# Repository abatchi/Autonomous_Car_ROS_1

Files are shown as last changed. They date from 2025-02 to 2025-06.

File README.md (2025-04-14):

# Autonomous Systems Project Team 08

# 🚀 Milestone 2

## 📌 Overview
Milestone 2 focuses on enhancements in software, simulation, and Hardware testing of the vehicle and motors. This phase includes crucial improvements in **Teleop**, **OLR (Open Loop Response)**, and system integration.

## 📁 Project Structure
The following key components are included in this milestone:

- **`python_scripts/`**: Contains essential scripts for teleoperation and OLR.
- **`launch/`**: Houses the necessary launch files for initializing the system.
- **Additional components**: Any supplementary configurations, ROS packages, or dependencies required for smooth operation.

# 📜 Milestone 1 Deliverables
For reference, the deliverables from Milestone 1 can be found in the following directories:

- **Hardware Deliverables:** Located in  
  📂 `Autonomous_Systems_Project_Team_08/Milestone1/Hardware_Milestone_01_Team_08/`
- **Simulation Deliverables:** Located in  
  📂 `Autonomous_Systems_Project_Team_08/Milestone1/Simulation_Milestone_01_Team_08/`

These directories contain all the necessary resources, including **hardware setup instructions for the Raspberry Pi 4B** and **simulation-based deliverables** from the first milestone.

## 📌 Next Steps
- Fine-tune the teleoperation and OLR functionalities.
- Validate performance through both **simulation** and **real-world testing**.
- Prepare documentation and further refinements for the next milestone.

---
📌 *This project is part of the Autonomous Systems course, developed by Team 08.* 🚀

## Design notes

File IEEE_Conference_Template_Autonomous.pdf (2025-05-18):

# 1/10 scale Autonomous Vehicle using ROS

1

st Nabil Hassan
Mechatronics Department
German University in Cairo Cairo, Egypt
nabil.hassan@student.guc.edu.eg

2

nd Yassin Eissa
Mechatronics Department
German University in Cairo Cairo, Egypt
yassin.eissa@student.guc.edu.eg

3

rd Mahmoud Assem
Mechatronics Department
German University in Cairo Cairo, Egypt
mahmoud.elkattan@student.guc.edu.eg

4

th Mohamed Mohy
Mechatronics Department
German University in Cairo Cairo, Egypt
mohamed.mohyeldin@student.guc.edu.eg

5

th Ahmed Akkad
Mechatronics Department
German University in Cairo Cairo, Egypt
ahmed.alakkad@student.guc.edu.eg

Abstract—This paper presents the development and implementation of a low-cost, small-scale autonomous ground vehicle designed for structured environments. The system adopts a modular architecture composed of a Raspberry Pi as the onboard computer for high-level processing and an Arduino Nano as the low-level controller for motor actuation and sensor interfacing. The vehicle integrates an Inertial Measurement Unit (IMU) for heading correction and wheel encoders for real-time speed estimation. A Stanley controller is utilized for lateral path tracking, while a PID controller governs longitudinal velocity. The software stack is built using the Robot Operating System (ROS), enabling efficient communication between system components and real-time decision-making. The proposed platform demonstrates reliable autonomous navigation capabilities and serves as an accessible and scalable solution for research and educational applications in the field of autonomous systems. Index Terms—Autonomous ground vehicle, ROS, Raspberry Pi, Arduino Nano, Stanley controller, PID control, IMU, wheel encoders, embedded systems, mobile robotics, path tracking.

I. INTRODUCTION
Autonomous vehicles are a rapidly evolving field at the intersection of robotics, artificial intelligence, and control systems. Their development promises to transform the way humans transport goods and themselves, offering significant advantages in safety, efficiency, scalability, and sustainability. While full-scale autonomous vehicles are the focus of major industrial efforts and commercial deployments, scaled-down autonomous platforms have emerged as powerful tools for research and education. Among these, 1/10 scale autonomous cars have gained considerable traction due to their affordability, safety, ease of experimentation, and strong community support.
A particularly prominent framework in this domain is the F1Tenth Autonomous Racing Platform, which provides a standardized, reproducible, and open-source platform for developing and benchmarking autonomous driving algorithms at 1/10 scale. Built on top of the Robot Operating System (ROS), the F1Tenth platform offers modular tools and software packages for perception, planning, and control, enabling researchers and students to implement real-world autonomous systems in a simulated or physical environment. The platform is supported by an international community and regularly features in autonomous racing competitions, fostering innovation and collaboration.
The development of autonomous vehicles, even at reduced scale, involves solving several complex tasks: localization, mapping, obstacle detection, trajectory planning, and control. These tasks must operate concurrently under real-time constraints and interact through a tightly integrated software architecture. ROS facilitates this integration by providing communication tools, simulation environments like Gazebo, and driver libraries for interfacing with sensors and actuators. As a middleware, ROS enables distributed development and modular testing, which are essential for the layered design of autonomous systems.
In this work, we present the design and implementation of a 1/10 scale autonomous vehicle built upon the principles of the F1Tenth platform and ROS architecture. The system was developed to perform autonomous lane-following and obstacle avoidance using real-time sensor feedback and closed-loop control. A Raspberry Pi 4 was used as the onboard high-level computer, running ROS nodes responsible for perception, planning, and control. Meanwhile, an Arduino Nano served as the low-level controller to directly manage motor speed and steering commands.
The localization system employed encoder data for speed estimation and an Inertial Measurement Unit (IMU) for heading correction, fused to provide accurate pose estimation in the absence of GPS. For lateral control, we implemented the Stanley Controller, a well-known algorithm used in path tracking for autonomous vehicles due to its simplicity and robustness to lateral errors. For longitudinal control, a classic PID controller was used to maintain desired velocity profiles. Together, these controllers enabled smooth, stable, and responsive vehicle behavior during navigation.
The platform was tested in both simulated environments and real-world indoor tracks, demonstrating its ability to track waypoints, navigate turns, and maintain lane stability in a reproducible manner. By adopting a system-level engineering approach, our implementation provides a practical foundation for further experimentation in areas such as real-time SLAM, deep learning-based perception, or multi-agent vehicle coordination.
This project contributes to the growing body of work that leverages 1/10 scale vehicles not only as educational tools but also as scalable prototypes for real-world autonomous driving systems. By aligning with the F1Tenth initiative, our system encourages reproducibility, benchmarking, and collaborative development, making it an ideal platform for future research and innovation in the field of autonomous systems.

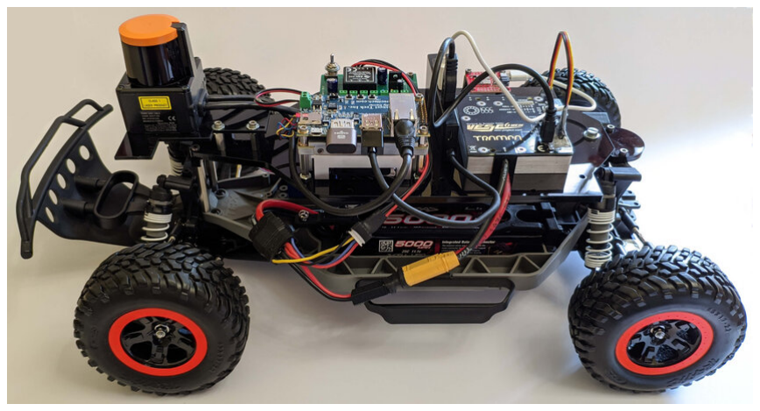
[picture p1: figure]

Fig. 1. F1Tenth Autonomous Car

II. LITERATURE REVIEW

Autonomous vehicles (AVs) rely on a combination of perception, localization, planning, and control modules to operate safely and efficiently. Recent research has explored innovations in each of these areas, with a particular emphasis on integrated system design, sensor fusion, and real-time decision-making. This section reviews recent contributions in control, localization, navigation, and integrated system architectures relevant to autonomous driving, including insights from the F1TENTH autonomous racing platform.

A. Control Modules in Autonomous Vehicles
The control system is responsible for executing planned trajectories while maintaining stability and safety. Modern approaches increasingly integrate perception and control to optimize performance in dynamic environments.
- DeepIPC: Deeply Integrated Perception and Control for an Autonomous Vehicle in Real Environments
[1] proposes an end-to-end model that tightly couples perception and control. The system utilizes RGB-D images for semantic segmentation and generates a bird’seye view (BEV) representation. Fused with GNSS and angular velocity data, the system predicts navigational waypoints, demonstrating high accuracy and robustness in complex, real-world scenarios.
- One Stack to Rule Them All: To Drive Automated Vehicles, and Reach for the 4th Level [2] presents a modular automated driving stack with components for localization, perception, planning, control, and safety. The framework emphasizes scalability and rapid prototyping, and it has been successfully deployed in urban passenger transport scenarios.
- Real-Time Control Strategies for High-Speed Autonomous Racing [3] demonstrates the F1TENTH platform’s capabilities in developing and testing control algorithms under extreme conditions. The study compares model predictive control (MPC) and pure pursuit controllers for aggressive cornering at speeds exceeding 8 m/s with 1:10 scale vehicles.
B. Localization Modules in Autonomous Vehicles
Precise localization is essential for reliable autonomous navigation, especially in GNSS-denied or cluttered environments.
- CV2X-LOCA: Roadside Unit-Enabled Cooperative Localization Framework for Autonomous Vehicles [4] introduces a cooperative localization method using cellular vehicle-to-everything (C-V2X) communication. The system achieves lane-level accuracy in GNSS-challenged environments by exploiting channel state information from nearby roadside units.
- A Survey on Localization for Autonomous Vehicles
[5] provides a comprehensive overview of state-of-theart localization techniques, analyzing sensor-based, mapbased, and learning-based methods. It highlights the trade-offs in terms of accuracy, robustness, and computational requirements, and underscores the growing importance of sensor fusion.
C. Navigation Modules in Autonomous Vehicles
Navigation modules generate feasible and safe trajectories while adapting to dynamic surroundings. Recent efforts focus on combining classical algorithms with AI-based learning methods.
- Navigation of Autonomous Light Vehicles Using an Optimal Trajectory Planning Algorithm [6] presents a trajectory planning framework that accounts for energy efficiency, localization, mapping, and obstacle avoidance. The algorithm improves path optimality for lightweight AV platforms.
- Hierarchical End-to-End Autonomous Navigation Through Few-Shot Learning [7] explores a hybrid framework that integrates few-shot learning with classical motion planning. The hierarchical structure enables AVs to generalize to new environments with minimal retraining, offering a promising direction for scalable navigation systems.
- Minimum-time Trajectory Planning for Autonomous Racing [8] implements a time-optimal racing line generation method on the F1TENTH platform. The approach combines Bezier curve optimization with vehicle dynam- ´ ics models, achieving lap times within 97% of human expert drivers in scaled environments.
D. Integrated Architectures for Autonomous Vehicles Seamless integration of localization, control, and navigation modules is critical for real-time autonomy. Modular and scalable system designs enable deployment across diverse platforms.
- System, Design, and Experimental Validation of Autonomous Vehicle Architectures [?] details a distributed architecture with modular components for perception, planning, and control. The system emphasizes sensor fusion for robust localization and has been validated in multiple operational scenarios.
- One Stack to Rule Them All [2], revisited here for its integrated design, further demonstrates how modular architectures can support real-world autonomy, including safety-critical applications and rapid experimental iterations.
- The F1TENTH Autonomous Racing Ecosystem [9] presents an open-source hardware/software platform for developing autonomous racing algorithms. The system integrates ROS 2 with custom vehicle dynamics models, enabling real-time performance at 60 Hz update rates while maintaining sub-centimeter positioning accuracy through LiDAR-based localization.

II. METHODOLOGY
The development of our 1/10 scale autonomous vehicle was approached through several key phases, beginning with hardware fabrication and basic system setup, progressing through simulation and control architecture design, and culminating in real-world testing and system integration using the Robot Operating System (ROS) framework.
A. Hardware Fabrication and Initial Setup
The project commenced with the physical fabrication of a 1/10 scale vehicle chassis, which was designed and 3D-printed in-house. The drivetrain consisted of a high-torque 1100KV Brushless DC (BLDC) motor controlled via an Electronic Speed Controller (ESC), and a servo motor for steering actuation. Both actuators were interfaced with an Arduino Nano microcontroller for low-level Pulse Width Modulation (PWM) control. A Raspberry Pi 4B running Debian Buster was installed as the high-level computing unit to interface with ROS and run control and localization nodes.
Concurrently, the software environment was prepared. The F1Tenth-inspired vehicle model was initially tested in the Gazebo simulator using an Audi R8 model. A “Hello World” ROS node was executed on both the Raspberry Pi and the host Ubuntu machine to verify the correct setup and inter-device communication.
B. Basic Control Nodes and Motor Testing
Following successful system initialization, two ROS nodes were developed and tested on the Ubuntu machine, which hosted the Gazebo environment:
- Open Loop Response Node (OLR): This node commanded the vehicle to move in a straight line at constant speed without feedback.
- Teleoperation Node: This node enabled keyboard-based manual control of the vehicle’s speed and steering.

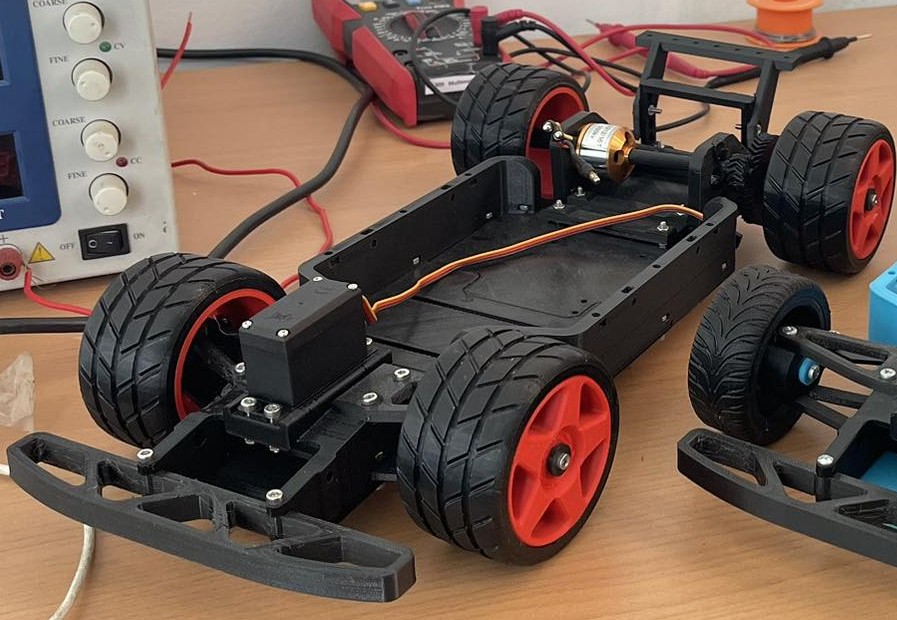
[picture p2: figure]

Fig. 2. The 1/10 3D printed Model

These nodes were integrated into a single roslaunch file that initialized the Audi R8 Gazebo model, OLR, and teleoperation simultaneously, enabling coordinated testing of the simulated environment. In parallel, motor testing was conducted on the physical hardware. The Arduino Nano was programmed to send PWM signals to the ESC and servo motor, allowing manual control and validation of actuator response.

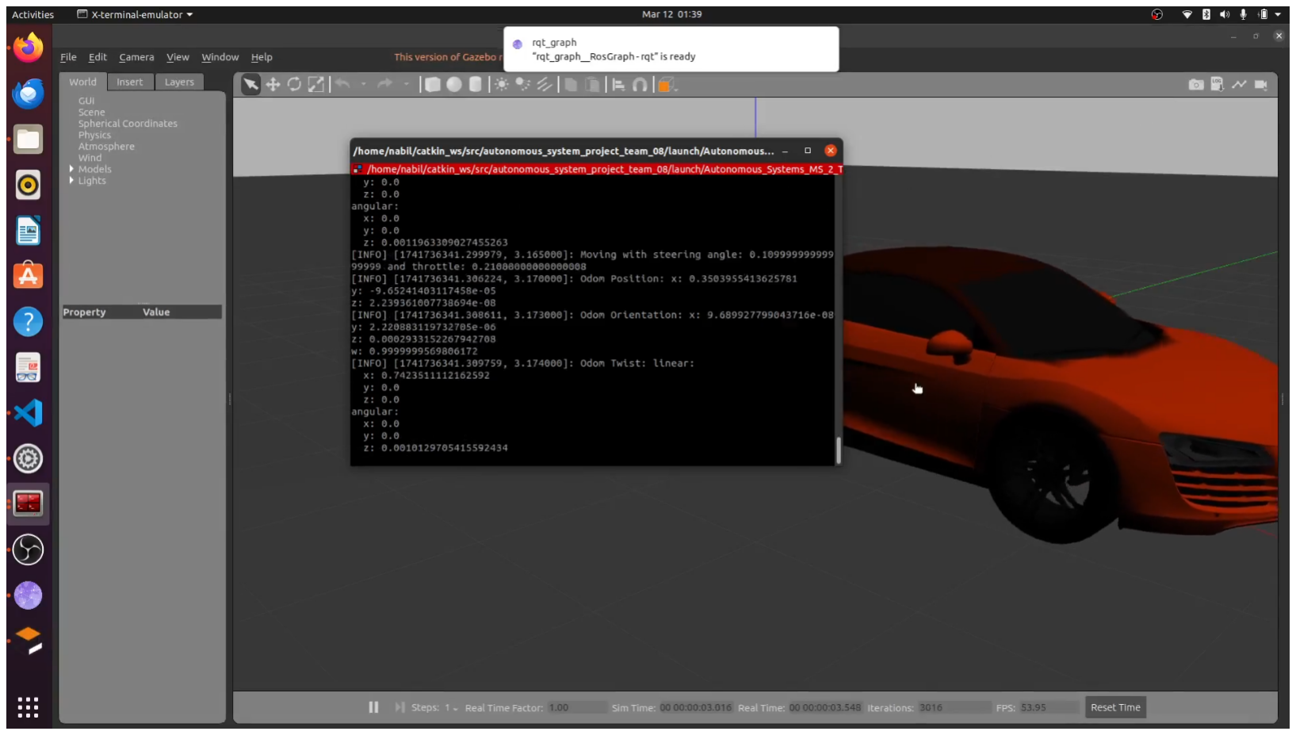
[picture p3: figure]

Fig. 3. Audi R8 in Gazebo

C. Closed-Loop Control Development

Subsequent work focused on designing and implementing closed-loop control systems. Two control ROS nodes were developed:
- Speed Controller Node: A feedback controller that regulated the vehicle’s linear velocity using encoder readings.
- Lateral Controller Node: A PID-based controller that maintained the vehicle’s lane position using a simple error-based heading correction scheme.
These control nodes were integrated into a new roslaunch file alongside the Gazebo vehicle model. Vehicle start and target positions were set using rosparam. The control algorithms were validated in simulation across various target positions within an empty Gazebo world to cover the entire vehicle workspace.
An updated teleoperation node from Milestone 2 (MS 2) was also re-integrated, now capable of sending desired speed and steering commands to the Arduino via USB serial communication. On the Arduino side, a proportional controller was implemented to regulate PWM signals sent to the actuators based on the target commands. To achieve accurate feedback control, encoders were added to both the BLDC motor and the steering mechanism for real-time velocity and angle measurement.

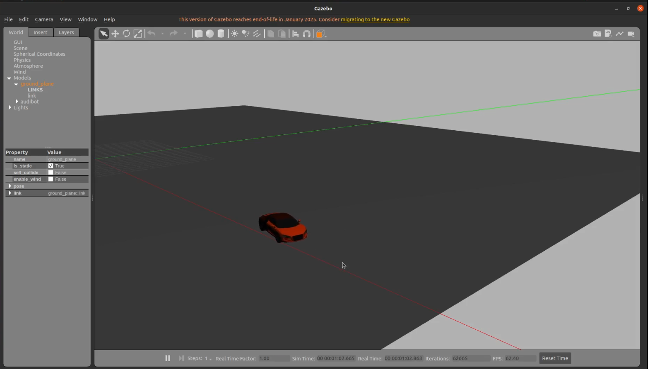
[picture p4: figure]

Fig. 4. Lateral & Longitudinal Control in Gazebo

D. Planning and Map Integration
A scaled track was designed with two lanes and known obstacle positions. The map was recreated in the Gazebo simulator, with all obstacles placed accurately. Due to dimensional mismatch (track designed for 1:14–1:18 scale), appropriate scaling was applied to ensure compatibility with the Audi bot Audi R8 in gazebo
A dedicated Planning ROS Node was developed to:
- Analyze the environment and obstacle positions.
- Generate a lane-following strategy with dynamic lane changes to avoid collisions.
- Plan a velocity profile appropriate for the path and send target commands to the Control ROS node.
A new launch file was created to initialize the Gazebo environment, vehicle model, controller, and planner. Initial vehicle pose, velocity, and planning parameters were set using
rosparam.
Hardware-wise, essential sensors were purchased and installed to allow full measurement of system inputs (velocity and steering angle) and states (heading and position). Arduino firmware was updated to acquire and transmit sensor readings to the Raspberry Pi via serial communication for further processing.
E. Localization and System Integration
To enable real-time feedback and noise-resilient estimation, a Localization ROS Node was implemented. This node:
- Subscribed to raw sensory data from the Arduino.

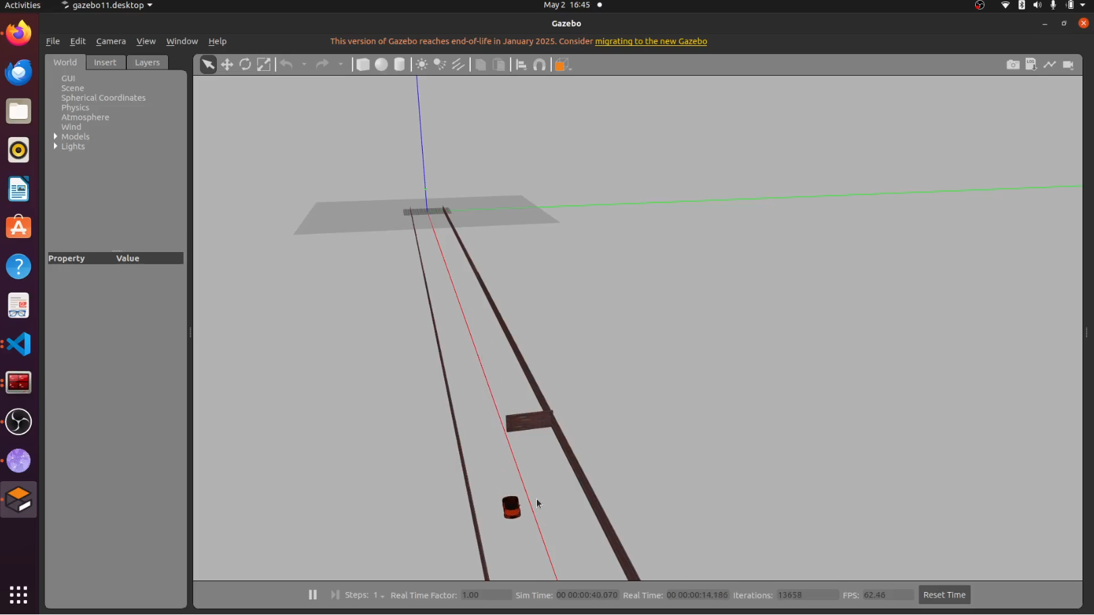
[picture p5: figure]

Fig. 5. Obstacle Avoidance Path Planning

- Injected synthetic Gaussian white noise based on the real sensors’ specifications.
- Filtered the noisy signals using appropriate filters.
- Published the filtered state estimations to the Control node.

This Localization node was integrated into a consolidated roslaunch file along with the Gazebo model, planner, and controller. Gaussian noise parameters and initial conditions were specified using rosparam.
A custom PCB was designed and fabricated to consolidate all electrical wiring beneath the vehicle chassis, ensuring structural integrity and clean layout for testing.

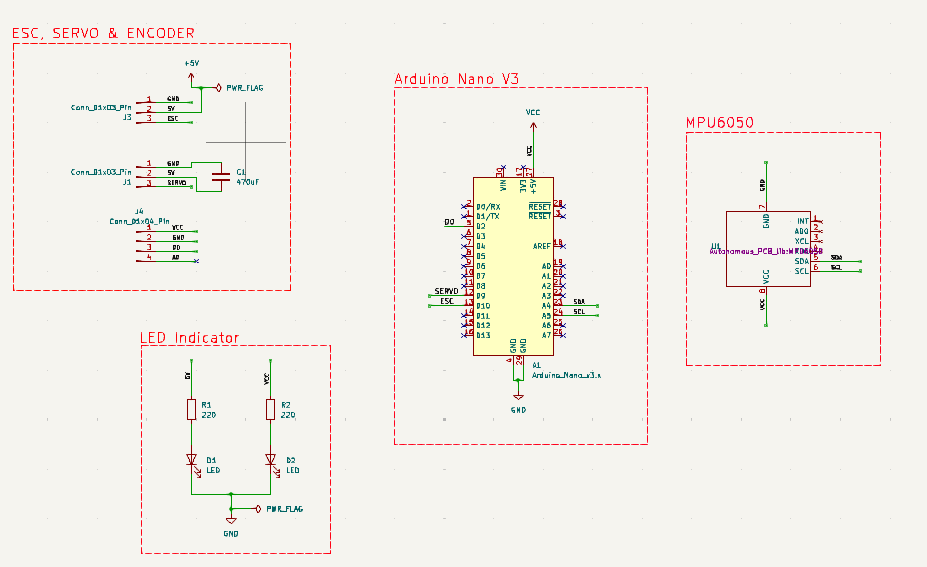
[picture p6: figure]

Fig. 6. The Schematic

In this phase, a Localization ROS node was designed and implemented to estimate the vehicle’s state in a manner that closely simulates real-world behavior. The node subscribes to essential dynamic parameters of the vehicle — such as velocity, steering angle, and heading — which are typically obtained from onboard sensors in practical scenarios.
To emulate realistic sensor performance within the simulation environment, white Gaussian noise was intentionally added to the measurement signals. The standard deviation of this noise was chosen based on typical values found in commercial sensor specifications. This step allowed us to evaluate the control algorithms under more realistic and challenging conditions, accounting for the presence of measurement uncertainty.

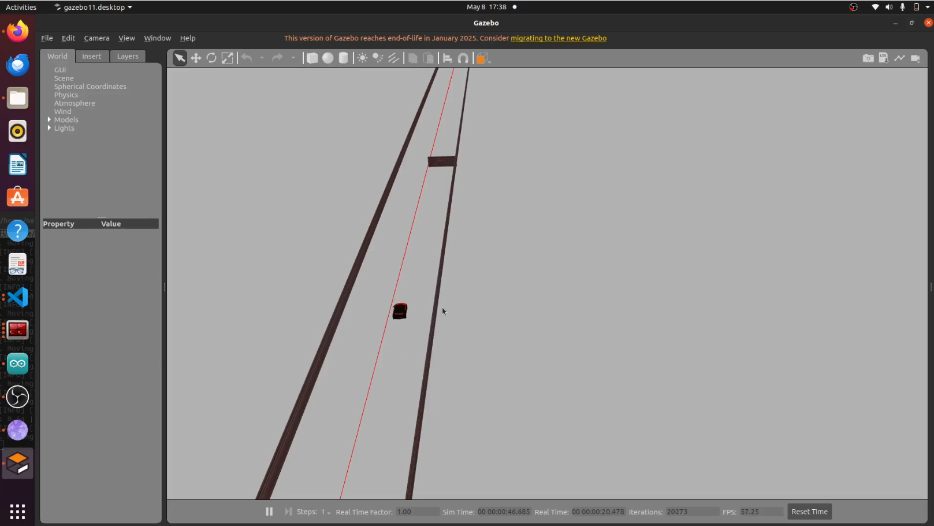
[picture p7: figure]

Fig. 7. The filtered response using kalman filter

To recover accurate state information from the noisy inputs, a Kalman Filter was implemented within the Localization node. This filter efficiently fuses the noisy sensor data with a motion prediction model of the vehicle, providing more reliable state estimates. These filtered estimates were then published to the Control ROS node, which depended on clean and stable data for effective execution of control commands. The addition of the Kalman Filter affected the dynamic behavior of the vehicle due to the inherent smoothing and slight delay in the filtered signals. Consequently, the Stanley controller used for lateral path tracking had to be re-tuned. Specifically, its gain parameters were adjusted to compensate for the changes in signal dynamics and ensure that the vehicle could still follow the desired path accurately. This calibration was essential for maintaining precise lane-keeping and obstacle avoidance behavior within the simulated environment.

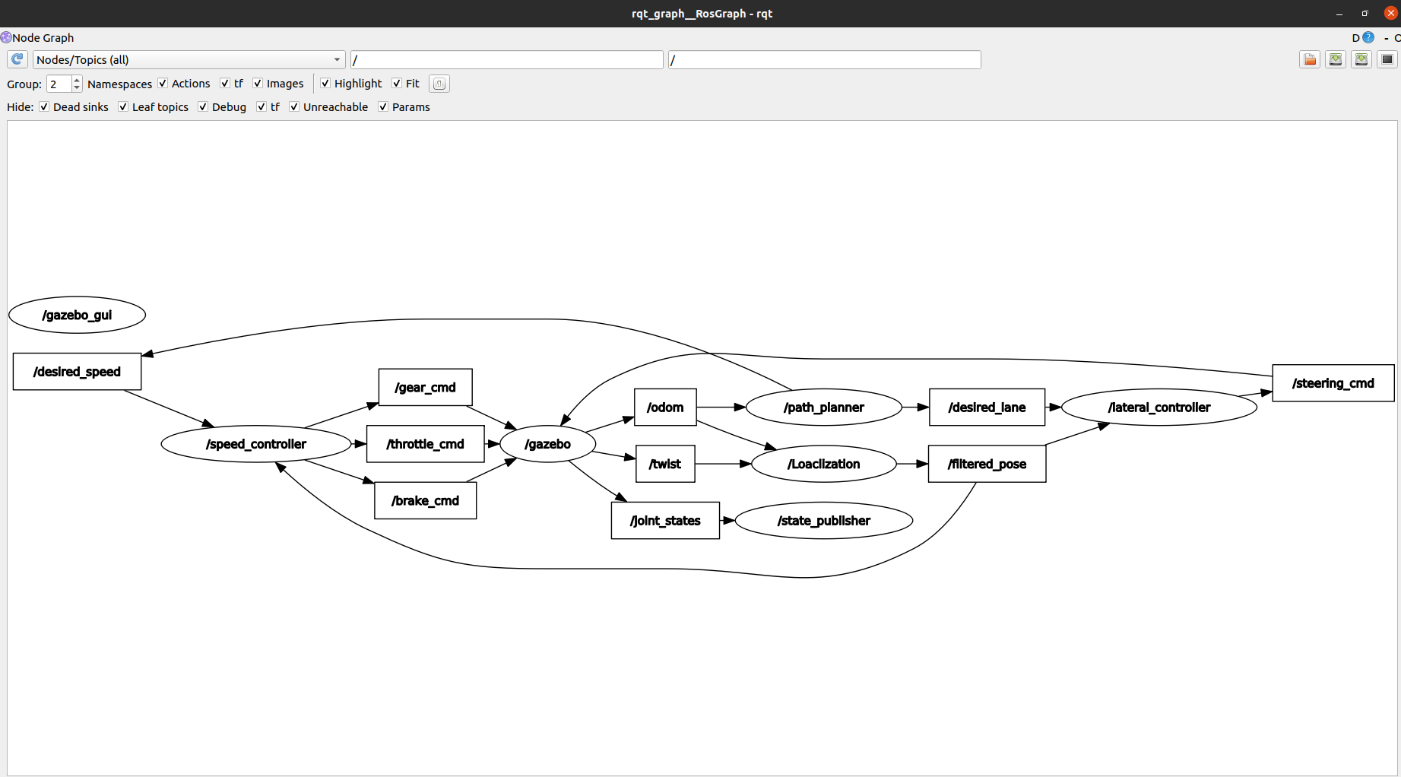
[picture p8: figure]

Fig. 8. The final rqt-graph

III. RESULTS
A. Simulation Results
1) Gazebo: The simulation environment was set up in Gazebo using a model of an Audi R8 model, within a custombuilt world that included both straight paths and obstaclepopulated lanes. This allowed for a comprehensive evaluation of the performance of the vehicle’s perception, control, and planning nodes under different driving conditions.

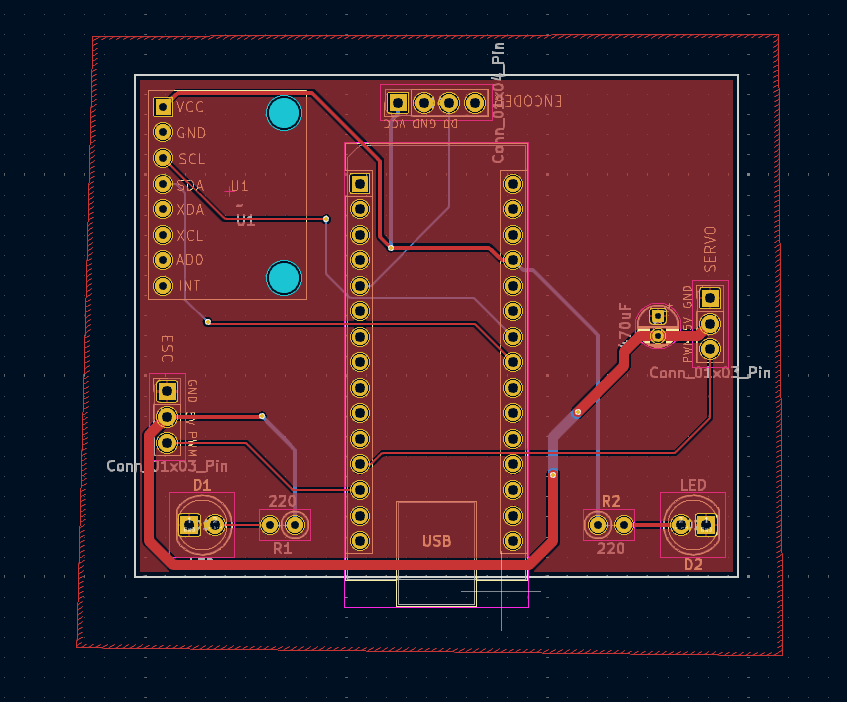
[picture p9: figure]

Fig. 9. The designed PCB

In the straight-line driving scenario, the vehicle exhibited smooth and steady motion with minimal deviation from the desired path, maintaining orientation within ±3 degrees of the reference heading. The open-loop response validated the correct actuation and model configuration within the Gazebo environment, while the closed-loop control (velocity PID and Stanley lateral controller) provided precise trajectory tracking. The Kalman Filter used in the localization node effectively suppressed simulated sensor noise (white Gaussian), providing clean and accurate estimates of the vehicle’s position and heading. This ensured that the control system received reliable feedback, contributing to stable and responsive vehicle motion throughout the simulation runs.
In the obstacle avoidance scenario, the planning node successfully generated a velocity profile and lane trajectory that enabled the car to detect, plan around, and avoid multiple static obstacles placed along the track. The coordination between the planning and control nodes was seamless, resulting in smooth lane changes and adaptive speed control without any collision or instability.
These simulation results confirmed the correctness, robustness, and consistency of the ROS-based architecture, validating the integration of control, planning, and localization subsystems in a virtual environment before hardware deployment.
2) Hardware Results: Following extensive validation in simulation, the developed autonomous vehicle system was deployed and tested on the physical 1/10 scale car platform. The objective was to evaluate the real-time performance of the control and planning algorithms under real-world conditions using actual sensors and actuators.
In the straight-line test, the car demonstrated highly stable motion with minimal steering drift. The measured heading deviation remained within ±3 degrees, consistent with the simulation results. This confirmed the effectiveness of both the speed controller and the lateral Stanley controller in maintaining the desired trajectory on the physical platform.

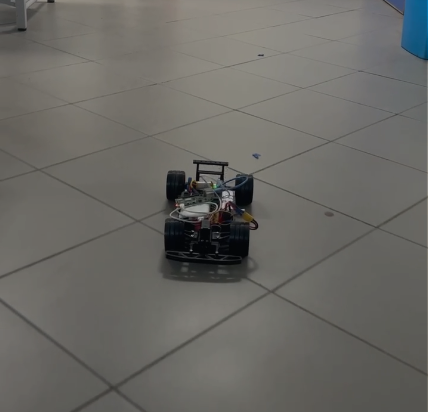
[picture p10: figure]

Fig. 10. The Straight line scenario

For obstacle avoidance, the autonomous car successfully executed smooth lane changes in response to the pre-mapped obstacle layout. The Planning ROS node, running onboard, generated suitable trajectories in real-time that were executed accurately by the control system. The system reacted promptly to upcoming obstacles by adjusting both the speed and lane position, replicating the simulation performance with high fidelity.
While some controller gain adjustments were necessary during hardware tuning—particularly for the Stanley controller due to latency and response non-idealities—the overall performance remained robust and consistent with expectations from simulation.
Overall, the hardware results confirmed that the integrated ROS system operated successfully, achieving autonomous navigation, stable control, and reliable obstacle avoidance under real-world conditions.

IV. CONCLUSION & FUTURE WORK

A. Conclusion
This project successfully demonstrated the development, simulation, and real-world testing of a 1/10 scale autonomous vehicle using the Robot Operating System (ROS). Through a systematic and modular approach, we implemented various ROS nodes that handled open-loop and closed-loop control, teleoperation, trajectory planning, and localization. Simulation results confirmed the correctness of our design, as the vehicle was able to maintain a straight trajectory with a deviation of less than 3 degrees and to perform obstacle avoidance maneuvers effectively. These promising results were validated in the hardware environment, where the vehicle exhibited steady control and reliable response to commands. The use of a Kalman filter in the localization node significantly reduced the effect of sensor noise, resulting in smoother

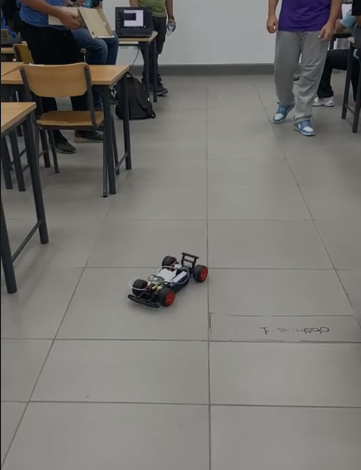
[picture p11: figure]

Fig. 11. The Obstacle Avoidance scenario

and more reliable estimation of the vehicle’s state. This enabled the controllers to function more accurately and ensured system stability across different scenarios. All nodes were integrated into a single launch file, allowing full simulation of the vehicle behavior in Gazebo, and later transitioning to partial hardware deployment.
Overall, the project validated the feasibility of using ROS for real-time control and planning in scaled autonomous vehicles, contributing to the broader body of research in F1Tenthscale robotic platforms.
B. Future Work
Although the core functionality was achieved, several areas can be explored to enhance system robustness and scalability:
- Sensor Fusion with Additional Modalities: Future iterations can integrate sensors such as LiDAR or stereo cameras to improve environmental awareness and dynamic obstacle detection.
- Real-Time SLAM and Mapping: Implementing SLAM techniques would allow the vehicle to operate in unknown or changing environments without relying on predefined maps.
- Advanced Path Planning: The current planning can be enhanced by incorporating algorithms like A*, RRT*, or hybrid A*, enabling more efficient and intelligent trajectory generation.
- Adaptive and Nonlinear Control: Replacing simple PID and Stanley controllers with more advanced techniques such as Model Predictive Control (MPC) or adaptive control could provide better handling under variable conditions.
- Cloud or Edge-based Processing: Offloading intensive computations to edge or cloud platforms can improve system performance and reduce the load on the onboard computer.
- Real-World Scalability Testing: Expanding the testing domain to larger tracks with moving obstacles or real-time interactive elements would further challenge and validate the system.
- Machine Learning Integration: End-to-end learning or reinforcement learning can be applied to train the vehicle to handle more complex behaviors and decision-making. This project lays the groundwork for scalable and extensible autonomous vehicle platforms and opens up new opportunities for integrating more advanced AI and robotics algorithms in the future.

REFERENCES

[1] O. Natan and J. Miura, “Deepipc: Deeply integrated perception and control for an autonomous vehicle in real environments,” arXiv preprint arXiv:2207.09934, 2022.
[2] S. Ochs, J. Doll, D. Grimm, et al., “One stack to rule them all: To drive automated vehicles, and reach for the 4th level,” arXiv preprint arXiv:2404.02645, 2024.
[3] M. O’Kelly, H. Zheng, D. Karthik, and R. Mangharam, “Real-time control strategies for high-speed autonomous racing,” in IEEE International Conference on Robotics and Automation (ICRA), pp. 1785–1791, 2021.
[4] Z. Huang, S. Chen, Y. Pian, et al., “Cv2x-loca: Roadside unit-enabled cooperative localization framework for autonomous vehicles,” arXiv preprint arXiv:2304.00676, 2023.
[5] A. names, “A survey on localization for autonomous vehicles,” IEEE Xplore, 2022.
[6] | Valera, F. Valero, M. Valles, ´ | et al., “Navigation of autonomous light
vehicles using an optimal trajectory planning algorithm,” Sustainability,
| vol. 13, no. 3, p. 1233, 2021.
[7] A. names, “Hierarchical end-to-end autonomous navigation through few-shot learning,” arXiv preprint arXiv:2409.14633, 2023.
[8] J. Brunn, M. O’Kelly, and R. Mangharam, “Minimum-time trajectory planning for autonomous racing,” IEEE Transactions on Intelligent Vehicles, vol. 7, no. 3, pp. 451–465, 2022.
[9] J. Pestana, M. O’Kelly, H. Zheng, and R. Mangharam, “The f1tenth autonomous racing ecosystem: From research to education,” in ACM/IEEE International Conference on Cyber-Physical Systems (ICCPS), pp. 1–12,
| 2023.

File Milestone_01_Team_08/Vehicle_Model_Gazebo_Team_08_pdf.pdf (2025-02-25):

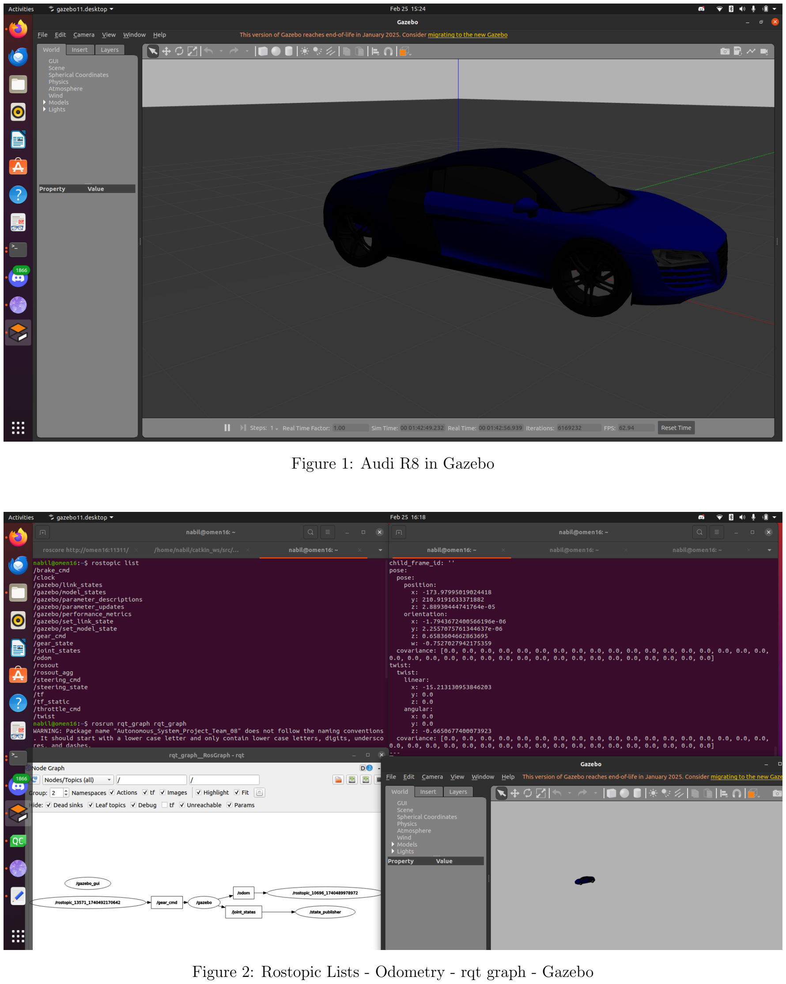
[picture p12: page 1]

Figure 1: Audi R8 in Gazebo

Figure 2: Rostopic Lists - Odometry - rqt graph - Gazebo

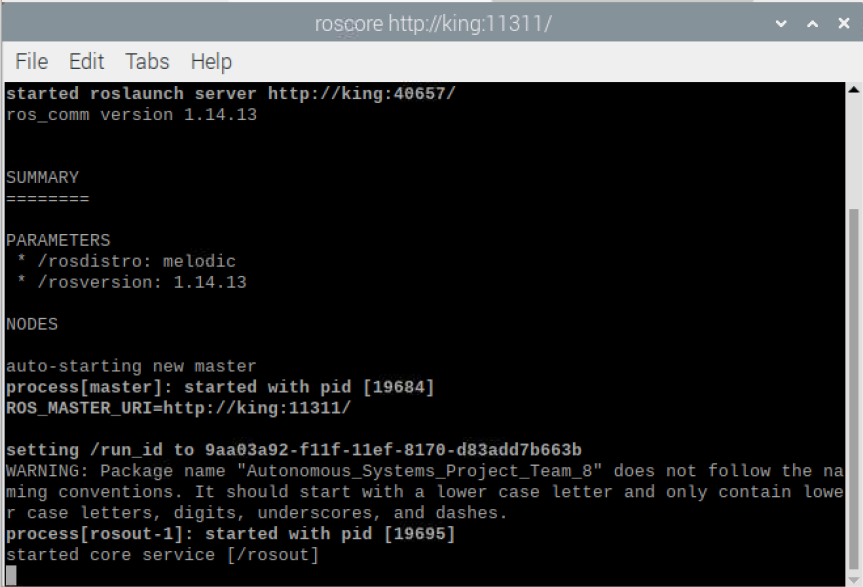
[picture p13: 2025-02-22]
Milestone_01_Team_08/Hardware_Milestone_01_Team_08/Hardware _roscore_Team_8.png.png

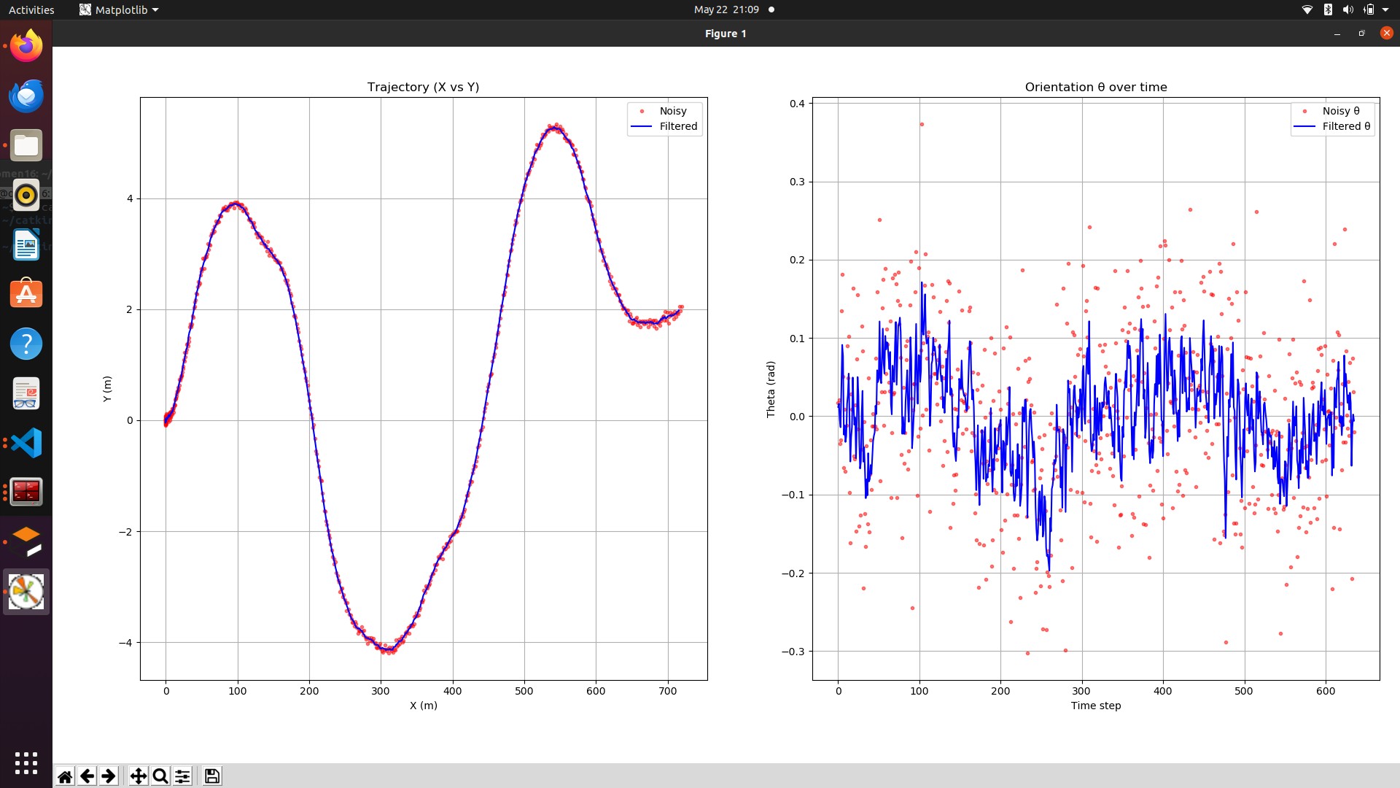
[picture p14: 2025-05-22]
Milestone_05_Team_08/Noisy_data_and_filtered_data_Simulation_2.png

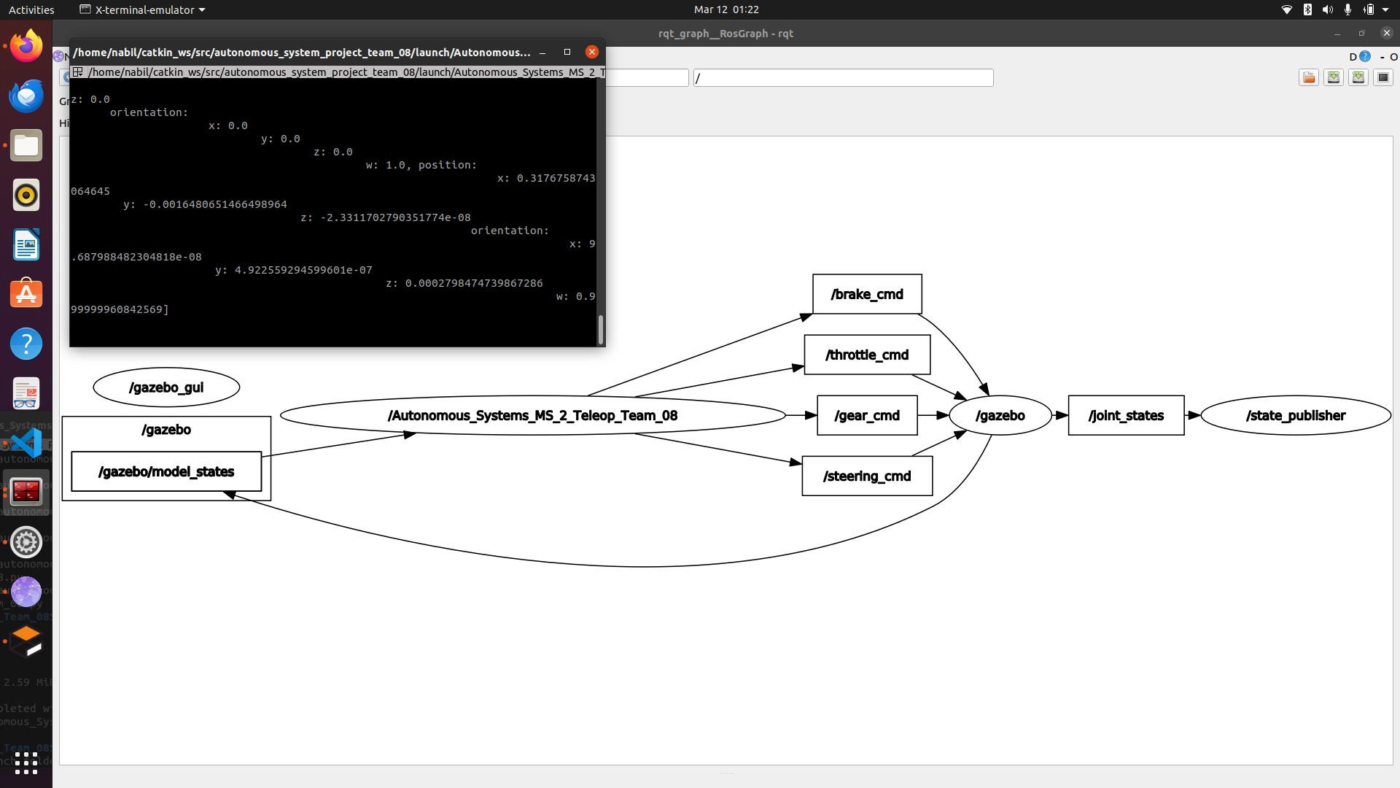
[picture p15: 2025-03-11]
Milestone_02_Team_08/Autonomous_Systems_Project_Simulation_Teleop_Team_08.png

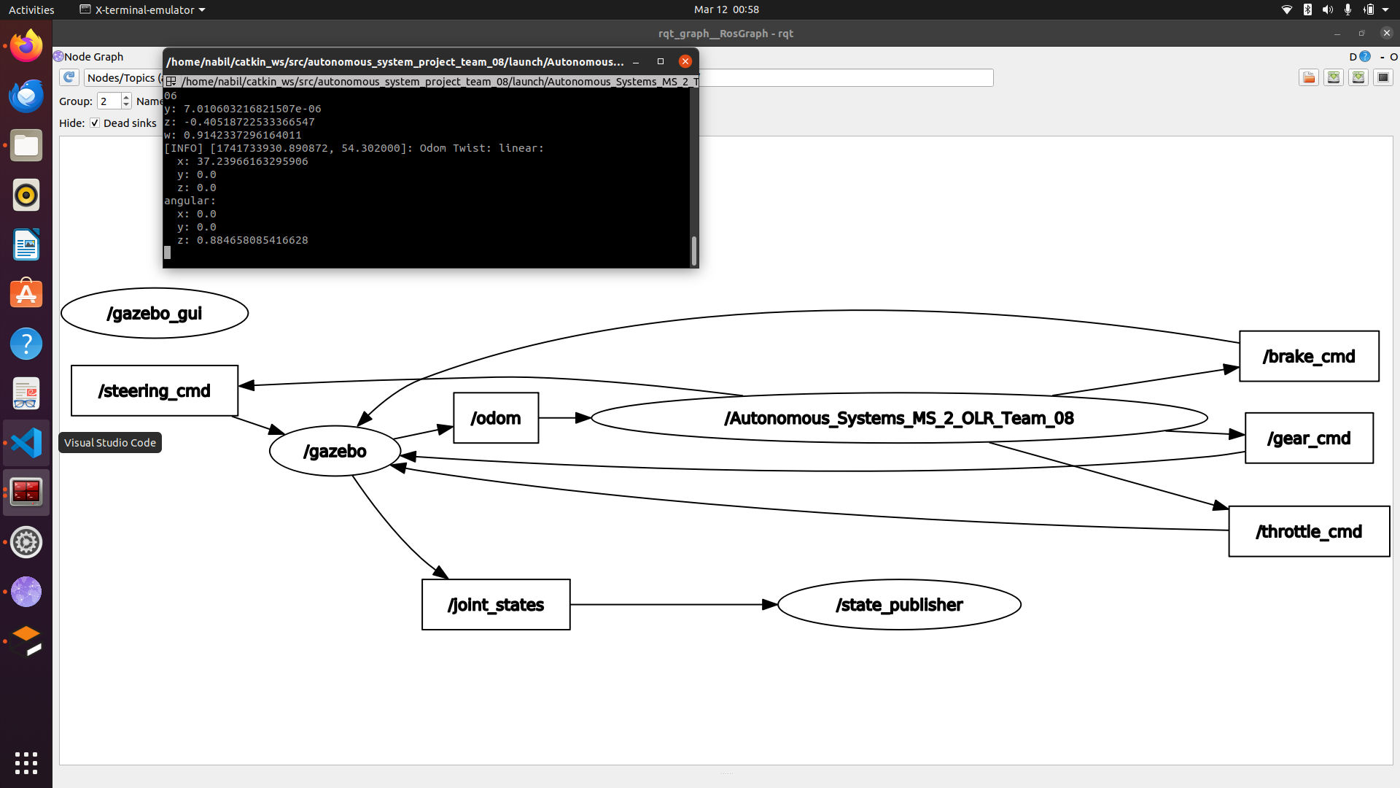
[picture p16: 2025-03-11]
Milestone_02_Team_08/Autonomous_Systems_Project_Simulation_OLR_Team_08.png

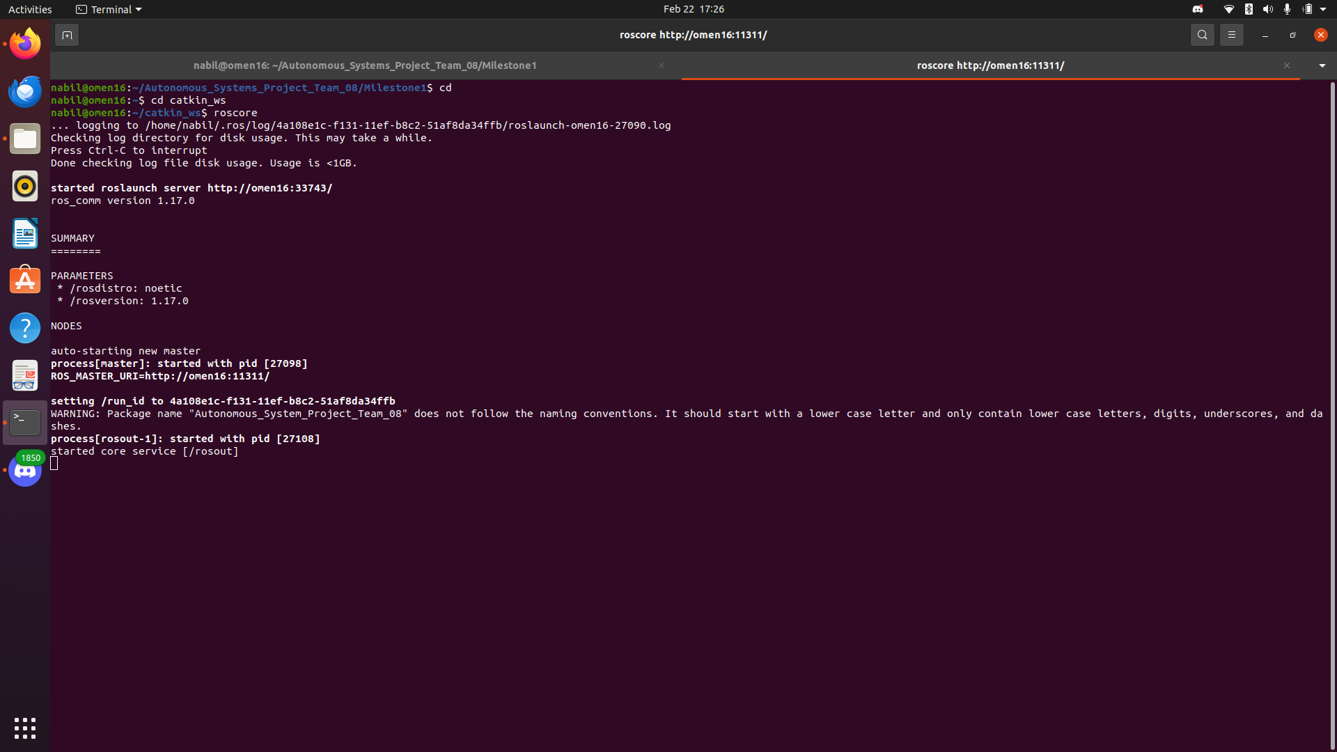
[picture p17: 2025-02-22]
Milestone_01_Team_08/Simulation_Milestone_01_Team_08/Simulation_Roscore_Team_08.png

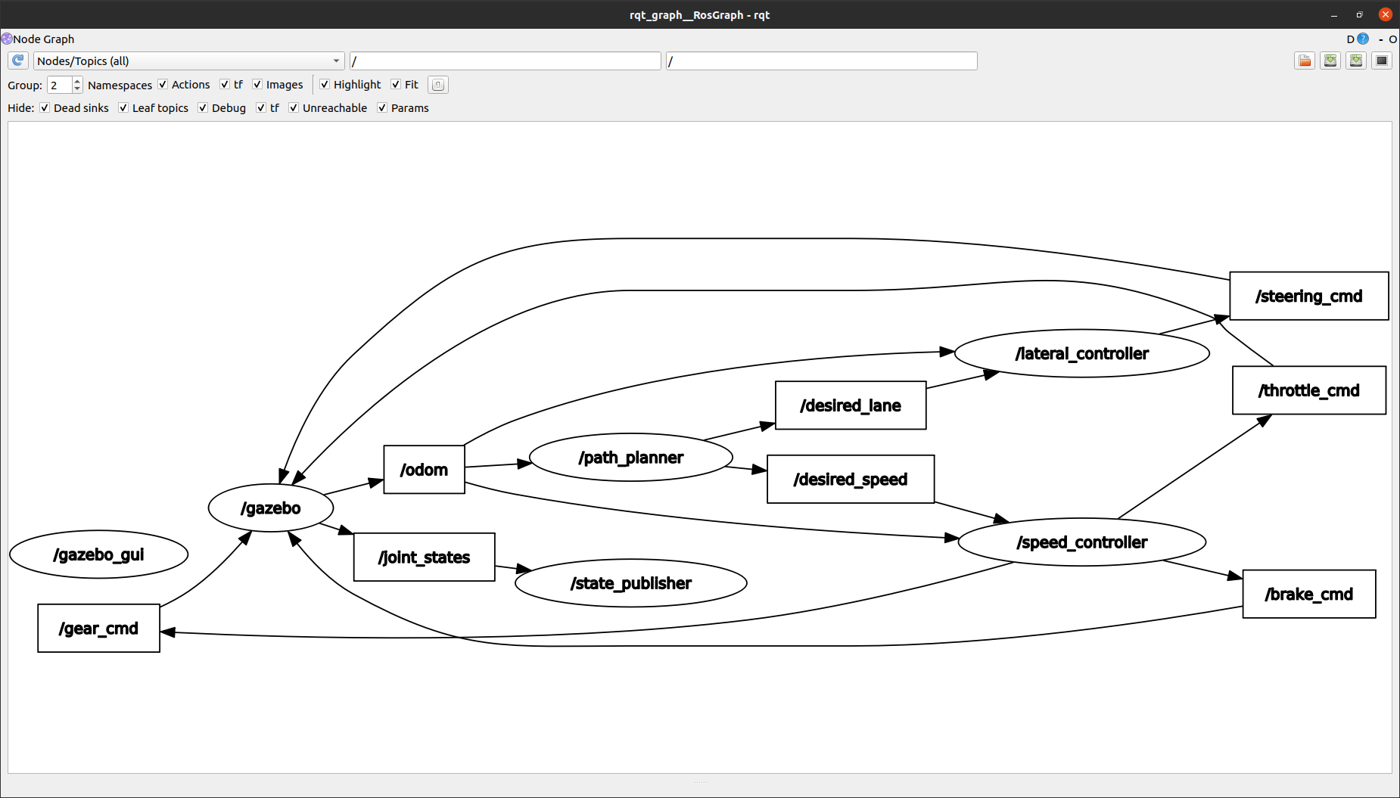
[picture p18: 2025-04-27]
Milestone_04_Team_08/Autonomous_Systems_Project_Simulation_MS_4_rqt_Team_08.png

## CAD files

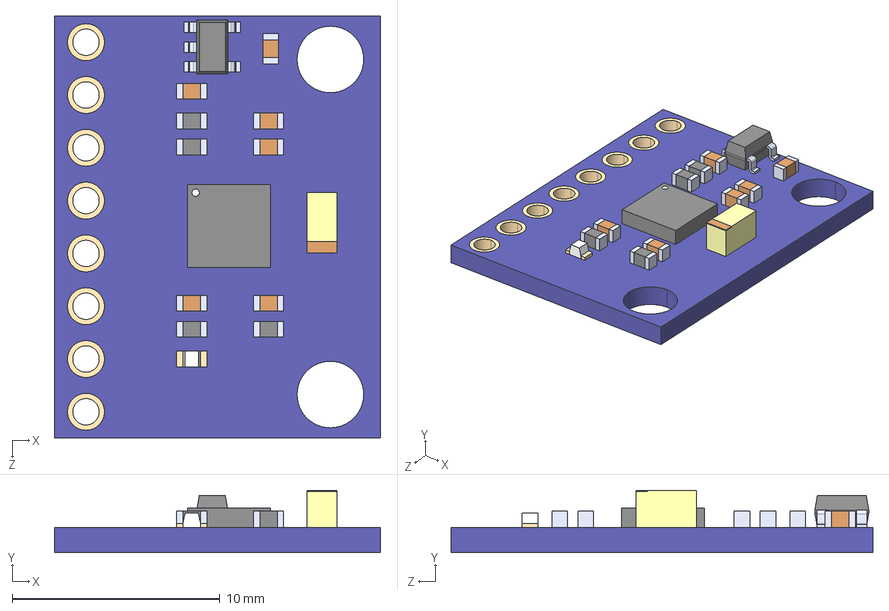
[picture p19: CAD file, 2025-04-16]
Autonomous_KiCAD8/OC09600--3DModel-STEP-269445.STEP
15.7 x 3.00 x 20.3 mm

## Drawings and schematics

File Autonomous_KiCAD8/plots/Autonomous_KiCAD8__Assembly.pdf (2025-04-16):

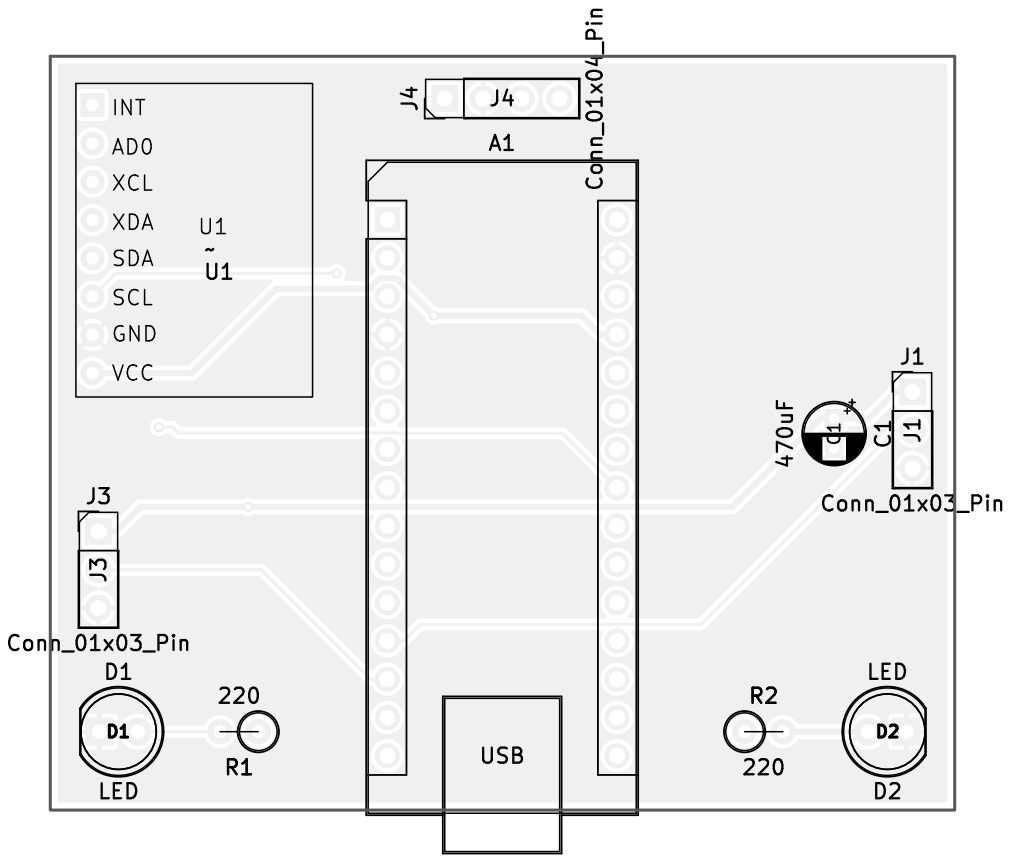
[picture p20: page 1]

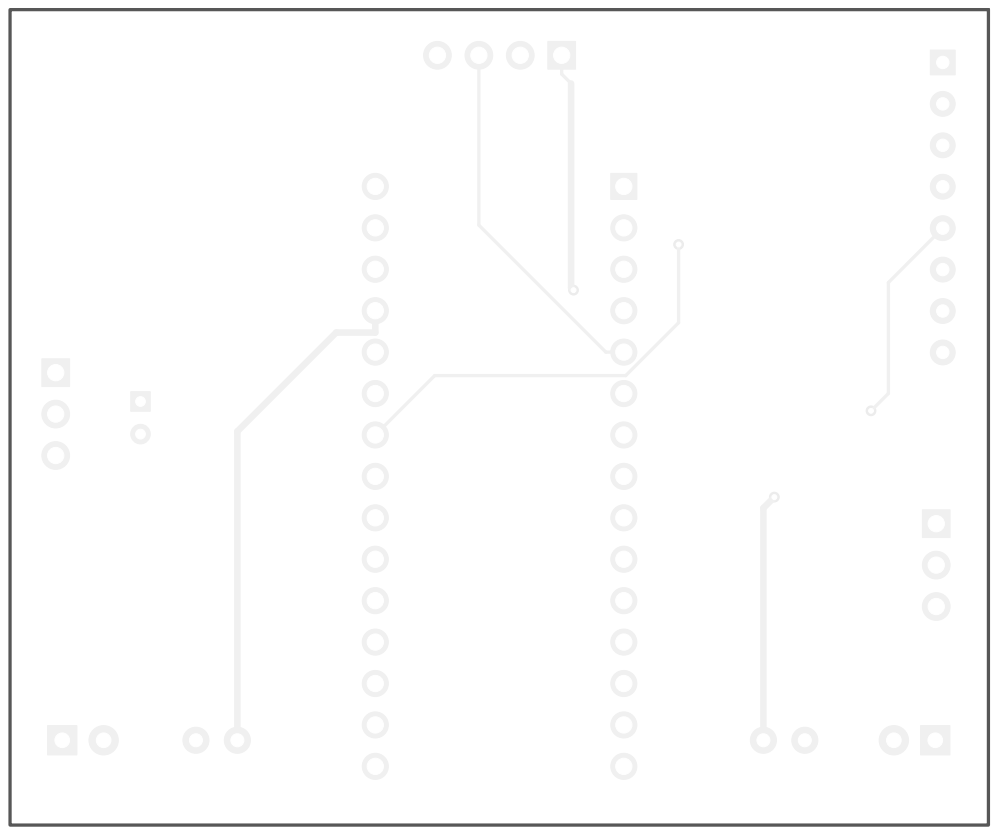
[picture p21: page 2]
D Date: KiCad; E.D.A. 8.0.6 Size: A4; Rev:; Id: 1/1 Title: File: Autonomous_KiCAD8.kicad_pcb Sheet: Black; And; White; BOT Board2Pdf:; Black; BOT -; Page 2/8

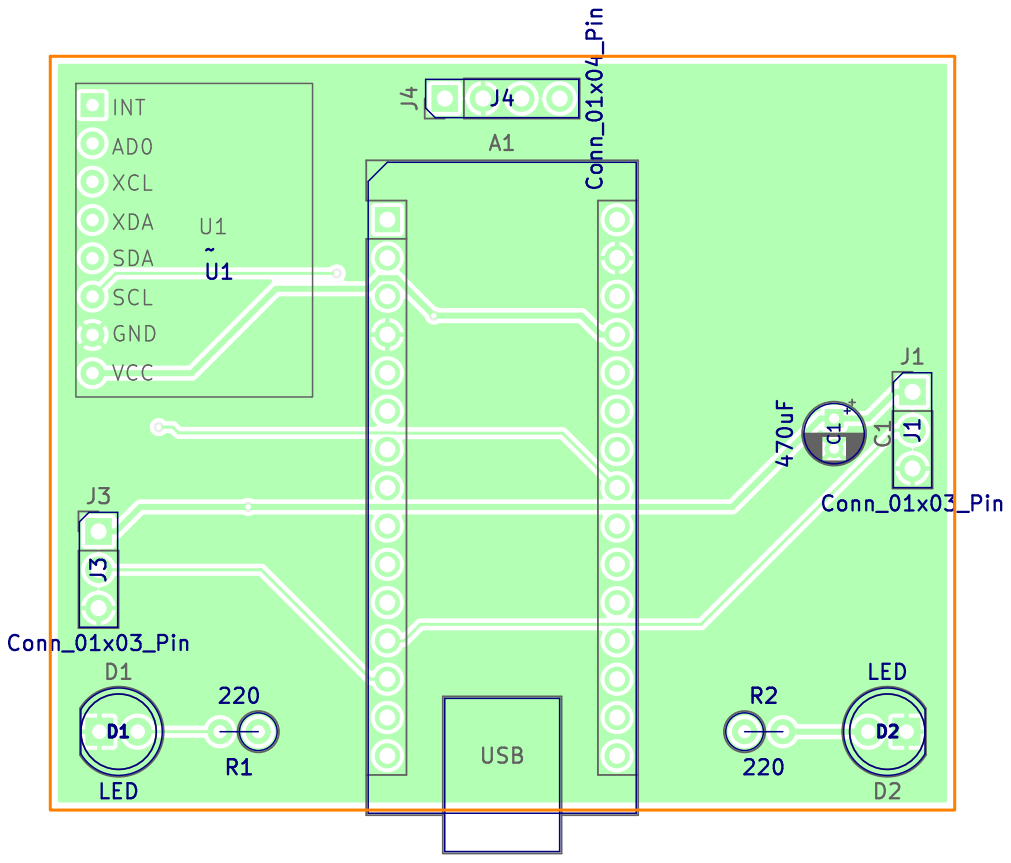
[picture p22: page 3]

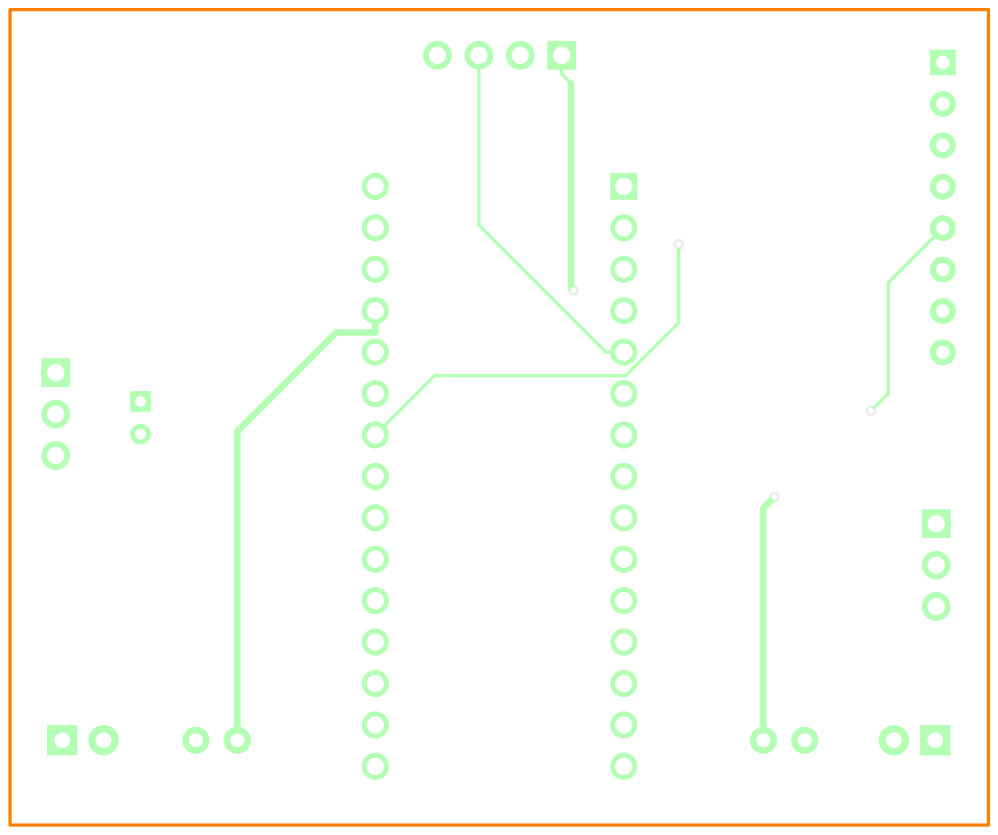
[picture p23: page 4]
D Date: KiCad; E.D.A. 8.0.6 Size: A4; Rev:; Id: 1/1 Title: File: Autonomous_KiCAD8.kicad_pcb Sheet: Colored; BOT Board2Pdf:; Colored; BOT -; Page 4/8

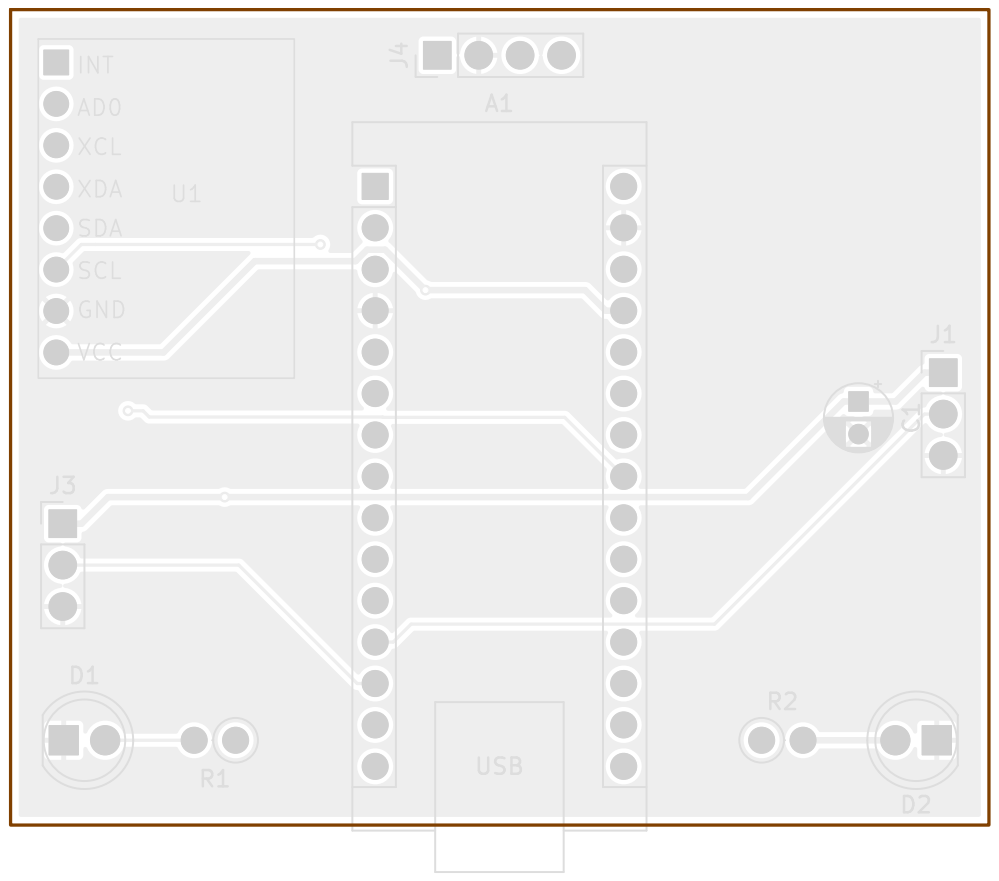
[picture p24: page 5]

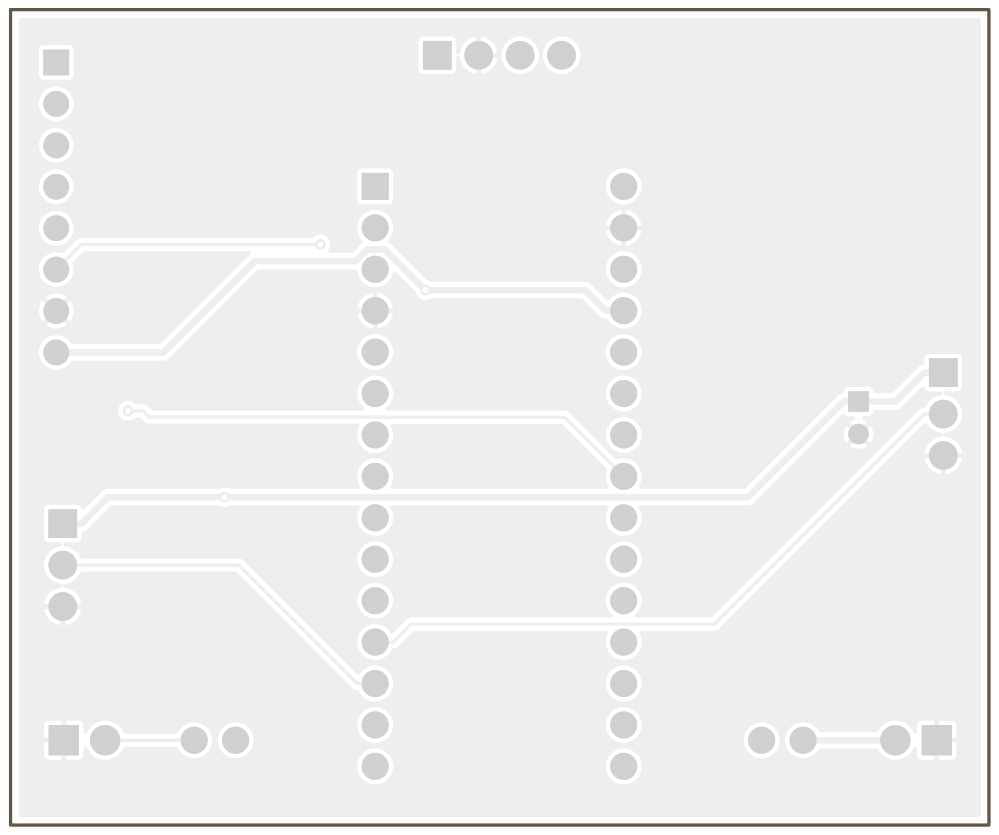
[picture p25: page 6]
D Date: KiCad; E.D.A. 8.0.6 Size: A4; Rev:; Id: 1/1 Title: File: Autonomous_KiCAD8.kicad_pcb Sheet: Light Colors; PCB; Paste; TOP; Board2Pdf:; Light Colors; TOP -; Page 6/8

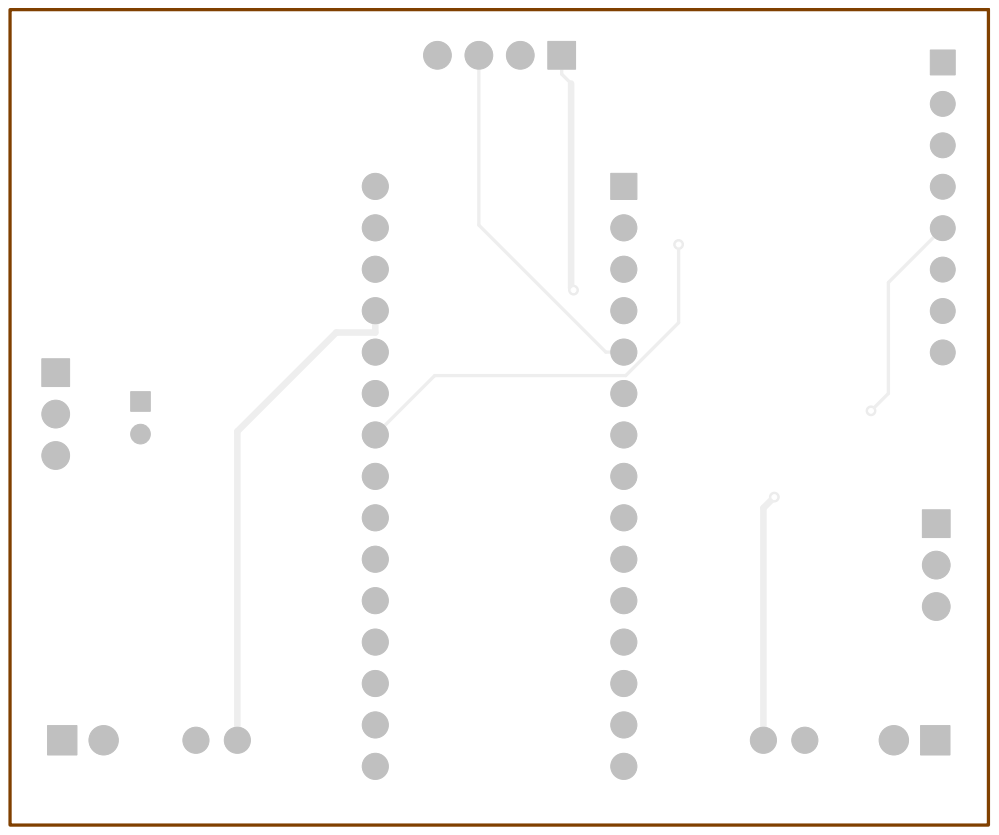
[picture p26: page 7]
D Date: KiCad; E.D.A. 8.0.6 Size: A4; Rev:; Id: 1/1 Title: File: Autonomous_KiCAD8.kicad_pcb Sheet: Light Colors; Placement; BOT Board2Pdf:; Light Colors; BOT -; Page 7/8

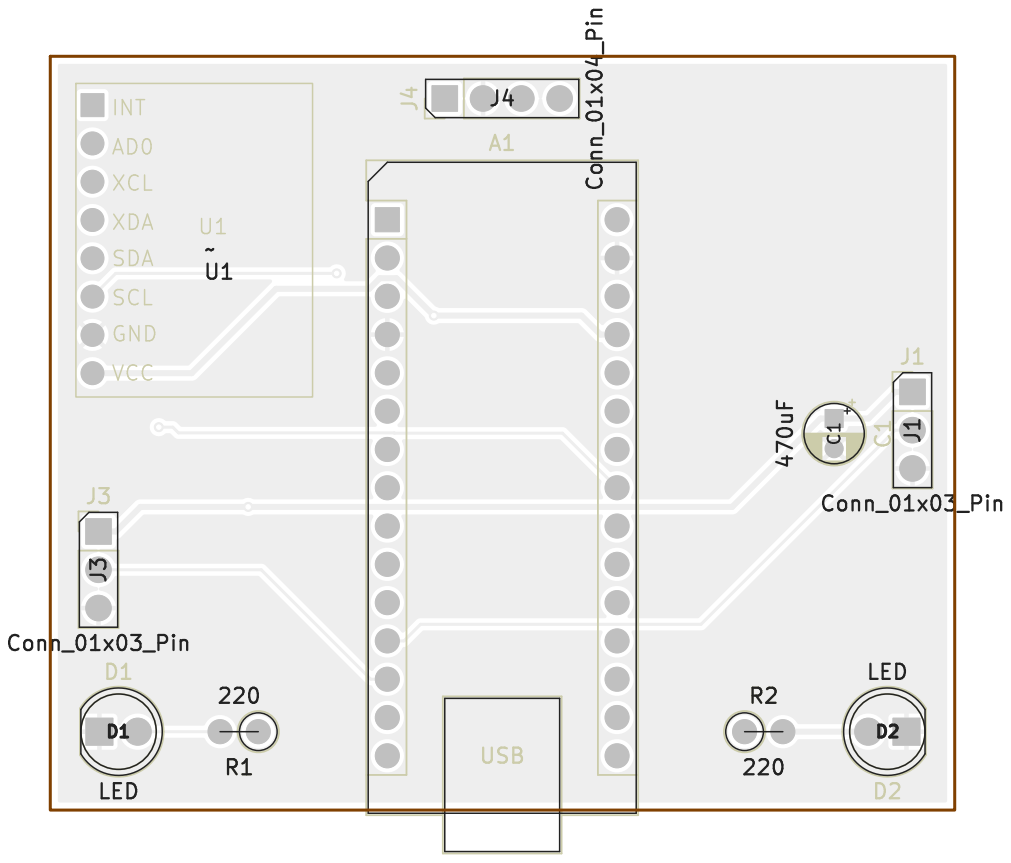
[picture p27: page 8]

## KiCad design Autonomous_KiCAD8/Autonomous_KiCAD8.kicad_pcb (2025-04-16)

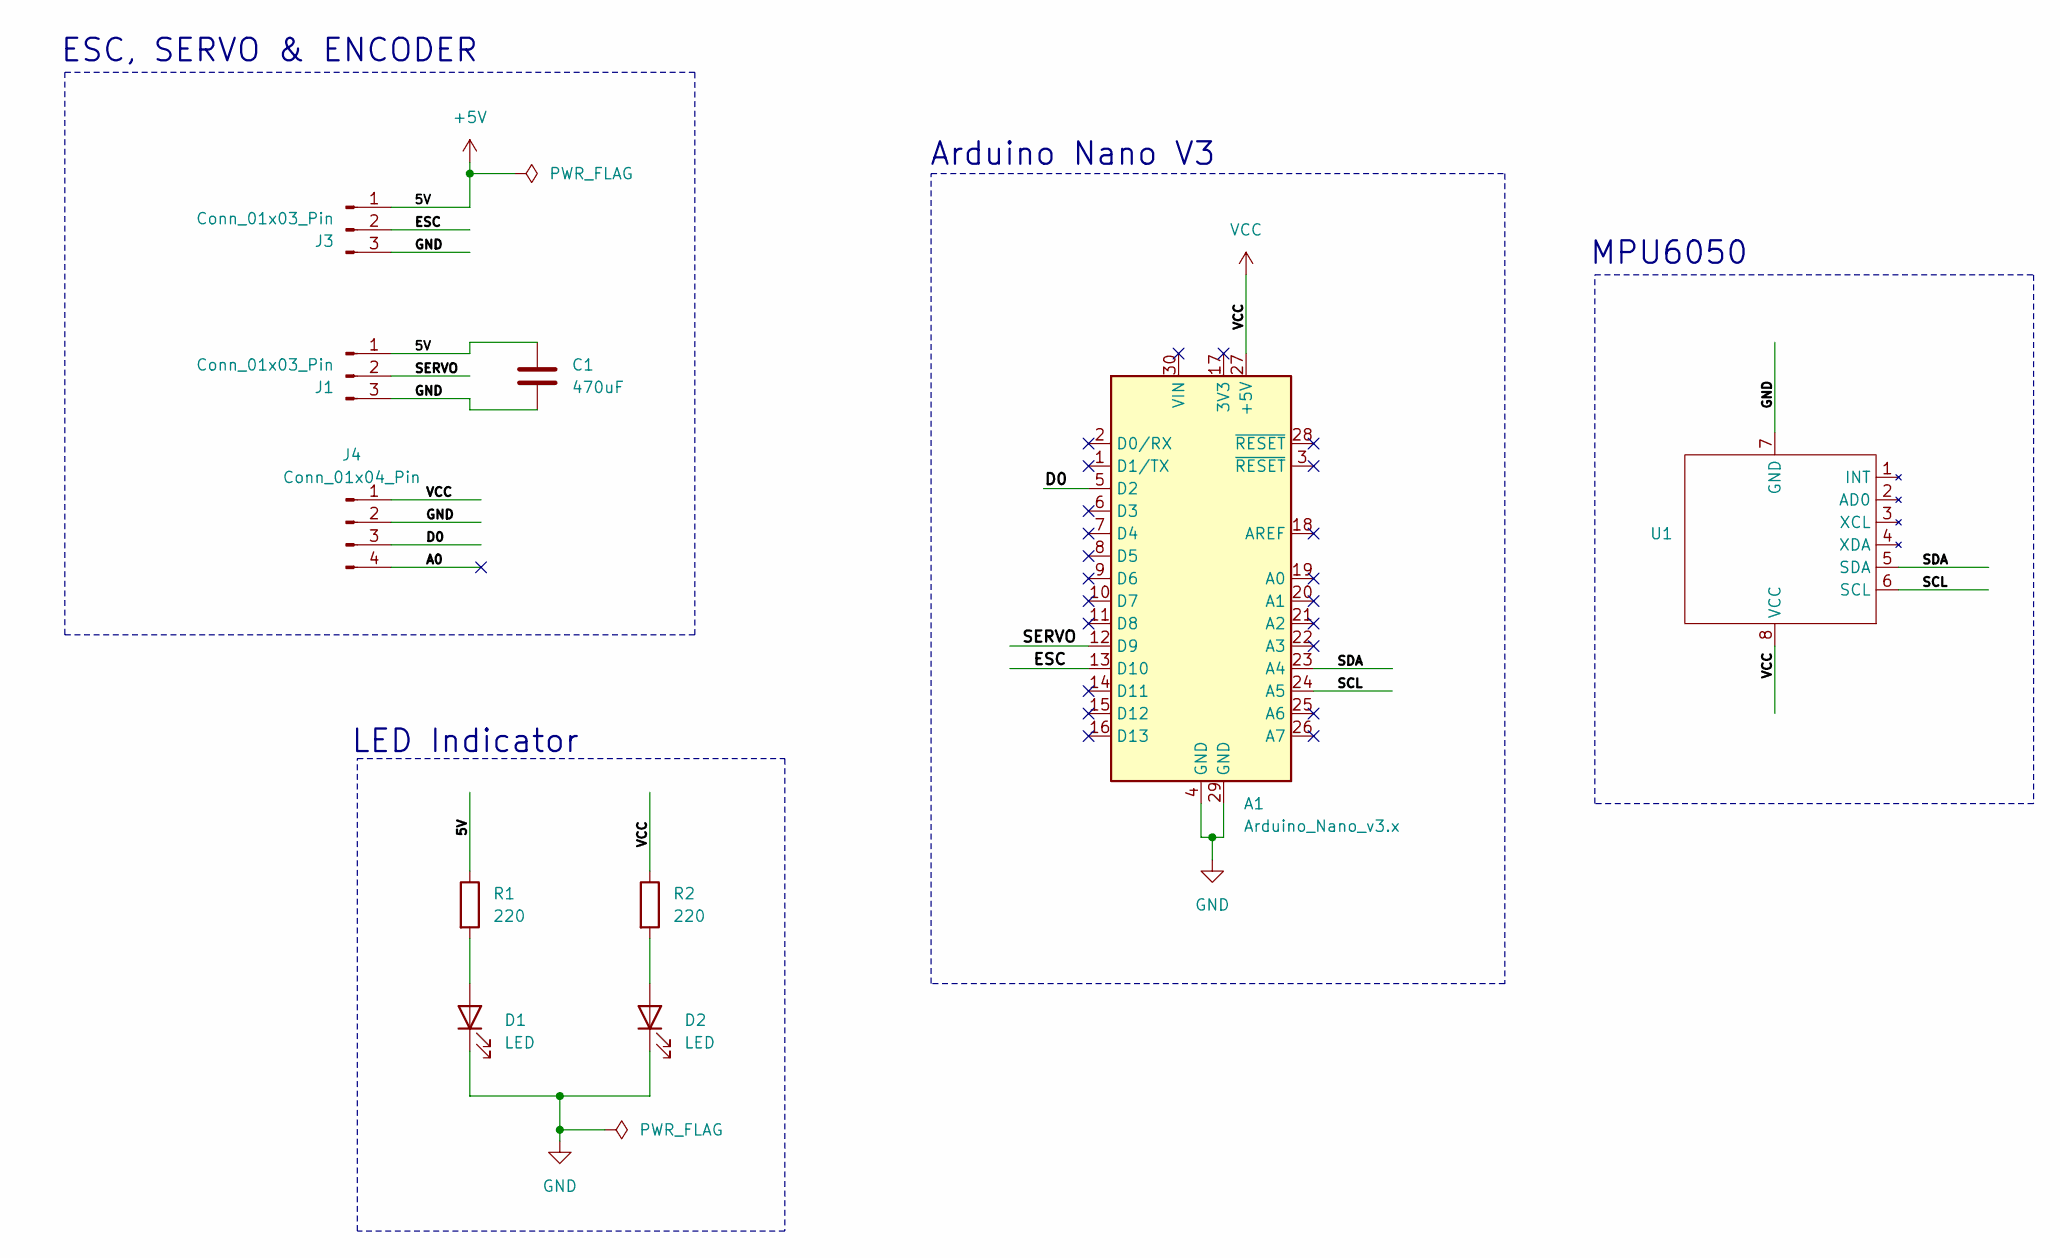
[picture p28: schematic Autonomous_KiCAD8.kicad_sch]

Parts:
A1: Arduino_Nano_v3.x; Arduino_Nano
C1: 470uF; CP_Radial_D4.0mm_P2.00mm
D1, D2: LED; LED_D5.0mm
J1, J3: Conn_01x03_Pin; PinHeader_1x03_P2.54mm_Vertical
J4: Conn_01x04_Pin; PinHeader_1x04_P2.54mm_Vertical
R1, R2: 220; R_Axial_DIN0207_L6.3mm_D2.5mm_P2.54mm_Vertical
U1: MPU6050

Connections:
+5V: C1.1, J1.1, J3.1, R1.1
/A0: J4.4
/D0: A1.5 (D2), J4.3
/ESC: A1.13 (D10), J3.2
/SCL: A1.24 (A5), U1.6 (SCL)
/SDA: A1.23 (A4), U1.5 (SDA)
/SERVO: A1.12 (D9), J1.2
GND: A1.4 (GND), A1.29 (GND), C1.2, D1.1 (K), D2.1 (K), J1.3, J3.3, J4.2, U1.7 (GND)
unnamed: D1.2 (A), R1.2
unnamed: D2.2 (A), R2.2
VCC: A1.27 (+5V), J4.1, R2.1, U1.8 (VCC)

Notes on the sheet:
LED Indicator
Arduino Nano V3
MPU6050
ESC, SERVO & ENCODER

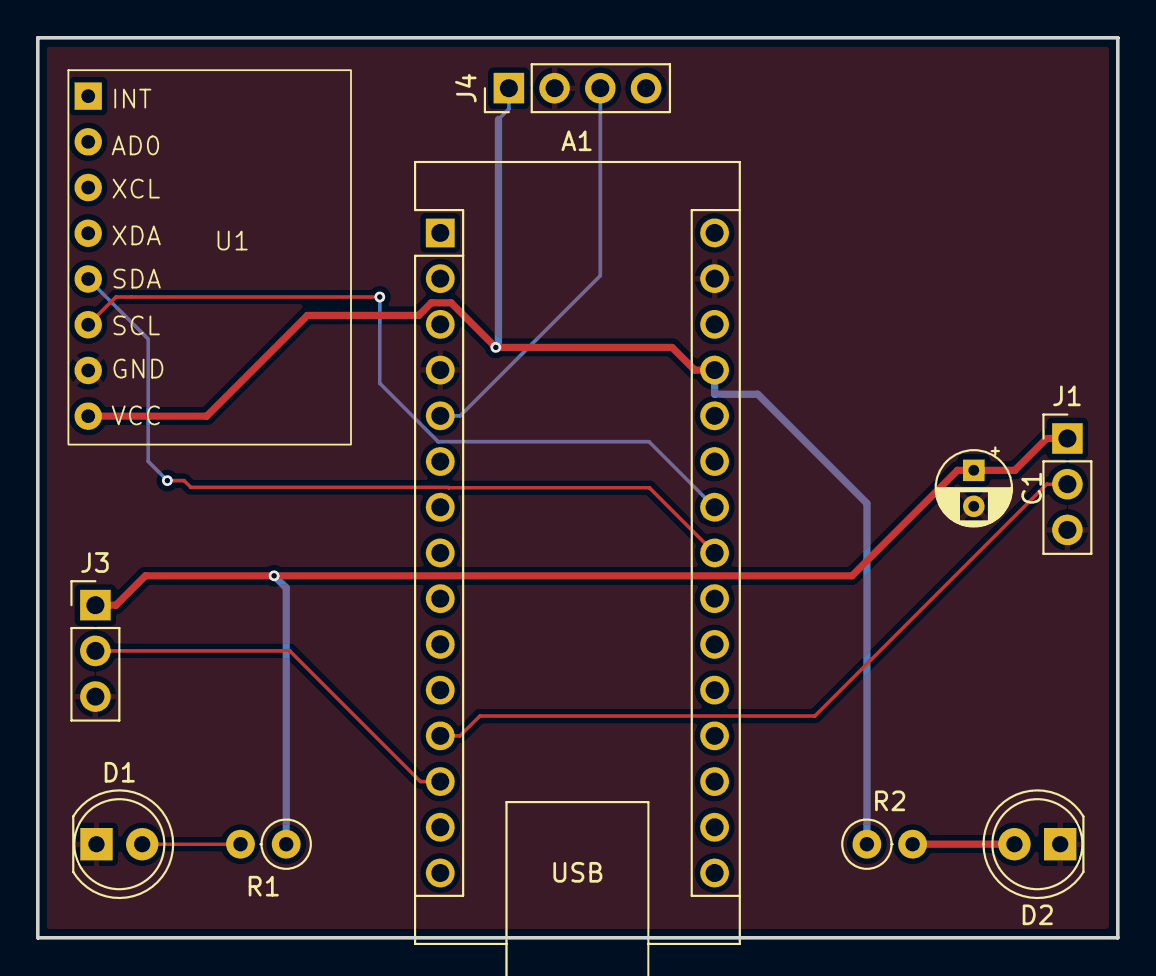
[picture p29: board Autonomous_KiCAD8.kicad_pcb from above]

Board: 2 copper layers, 60.0 x 50.0 mm, 10 parts (0 on the bottom side), 10 nets.

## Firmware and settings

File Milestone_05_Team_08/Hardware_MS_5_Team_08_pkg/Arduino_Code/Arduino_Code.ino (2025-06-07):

#include <Wire.h>
#include <Servo.h>

// === Servo & ESC ===
Servo steeringServo;
Servo esc;
const int servoPin = 10;
const int escPin = 9;


// === Servo limits (customized zero point and limits) ===
const int servoCenter = 120;
const int servoLeftLimit = 90;
const int servoRightLimit = 140;

// === ESC PWM range ===
const int minPulse = 1000;    // ESC min pulse (µs)
const int maxPulse = 1050;    // ESC max pulse (µs)

// === MPU6050 Yaw ===
long gyro_z_cal = 0;
int16_t gyro_z;
double dt;
double gyroYaw = 0;
const float GYRO_SCALE = 65.5;

// === Encoder ===
const int encoderPin = 2;
volatile long encoderTicks = 0;
unsigned long lastEncoderSend = 0;
const int ticksPerRev = 85;
const unsigned long encoderSendInterval = 100; // ms

// === Timing ===
unsigned long prevTime;

void setup() {
  Serial.begin(115200);
  Wire.begin();

  // ESC setup
  esc.attach(escPin);
  for (int i = 0; i < 50; i++) {
    esc.writeMicroseconds(minPulse);
    delay(20);
  }

  // Servo setup
  steeringServo.attach(servoPin);
  steeringServo.write(servoCenter);

  // MPU6050 setup
  setup_mpu_6050_registers();
  calibrateGyro();
  prevTime = micros();

  // Encoder setup
  pinMode(encoderPin, INPUT_PULLUP);
  attachInterrupt(digitalPinToInterrupt(encoderPin), encoderISR, RISING);
}

void loop() {
  // === Serial input ===
  if (Serial.available()) {
    String input = Serial.readStringUntil('\n');
    input.trim();

    if (input.indexOf(',') != -1) {
      int sep = input.indexOf(',');
      String angleStr = input.substring(0, sep);
      String throttleStr = input.substring(sep + 1);

      int angle = angleStr.toInt();
      float throttle = throttleStr.toFloat();

      // Clamp and write angle
      if (angle >= servoLeftLimit && angle <= servoRightLimit)
        steeringServo.write(angle);

      // Convert throttle [0.0 - 1.0] to pulse width
      throttle = constrain(throttle, 0.0, 1.0);
      int pulseWidth = minPulse + (int)(throttle * (maxPulse - minPulse));
      esc.writeMicroseconds(pulseWidth);
    }
  }

  // === Yaw computation ===
  dt = (micros() - prevTime) * 1e-6;
  prevTime = micros();

  read_gyro_z();
  gyro_z -= gyro_z_cal;
  double gyroRateZ = (double)gyro_z / GYRO_SCALE;
  gyroYaw += gyroRateZ * dt;

  // === Send yaw and encoder every 100ms ===
  unsigned long now = millis();
  if (now - lastEncoderSend >= encoderSendInterval) {
  lastEncoderSend = now;
    
  // if this doesn't work comment it and uncomment the one below it and try it
  noInterrupts();
    long ticks = encoderTicks;
    float rpm = (encoderTicks * 600.0) / 85.0;
    encoderTicks = 0;
  interrupts();

  // noInterrupts();
  // long ticks = encoderTicks;
  // encoderTicks = 0;
  // interrupts();

  // float rpm = (ticks * 600.0) / ticksPerRev;


  

  Serial.print(rpm, 2); // Send revolutions (2 decimal places)
  Serial.print(",");
  Serial.println(gyroYaw * -1);
}


  // Optional: maintain ~250 Hz loop
  while (micros() - prevTime < 4000);
}

// === MPU6050 Functions ===

void calibrateGyro() {
  for (int i = 0; i < 3000; i++) {
    read_gyro_z();
    gyro_z_cal += gyro_z;
    delay(3);
  }
  gyro_z_cal /= 3000;
}

void read_gyro_z() {
  Wire.beginTransmission(0x68);
  Wire.write(0x47); // Gyro Z register
  Wire.endTransmission();
  Wire.requestFrom(0x68, 2);
  gyro_z = Wire.read() << 8 | Wire.read();
}

void setup_mpu_6050_registers() {
  Wire.beginTransmission(0x68);
  Wire.write(0x6B);
  Wire.write(0x00); // Wake up
  Wire.endTransmission();

  Wire.beginTransmission(0x68);
  Wire.write(0x1B);
  Wire.write(0x08); // ±500°/s sensitivity
  Wire.endTransmission();
}

// === Encoder ISR ===
void encoderISR() {
  encoderTicks++;
}

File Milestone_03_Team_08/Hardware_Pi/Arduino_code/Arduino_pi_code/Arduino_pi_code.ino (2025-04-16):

#include <Servo.h>

Servo myServo; // Create Servo object
Servo esc;  // Create ESC object
String command = "";

void setup() {
  Serial.begin(9600);
  myServo.attach(9);  // Attach to pin D9
  esc.attach(10);
  myServo.write(120); // Center position
  Serial.println("Arming ESC...");
    
  // **Step 1: Arm the ESC (Throttle = 1000µs)**
  esc.writeMicroseconds(1000);  // Minimum throttle (ESC Off)
  delay(3000);                  // Wait 3 seconds
  Serial.println("ESC Armed!");

}

void loop() {
  if (Serial.available()) {
    command = Serial.readStringUntil('\n');

    if (command == "LEFT") {
      myServo.write(90);
      esc.writeMicroseconds(1000);
    } 
    else if (command == "RIGHT") {
      myServo.write(140);
      esc.writeMicroseconds(1000);
    } 
    else if (command == "CENTER") {
      myServo.write(120);
      esc.writeMicroseconds(1000);
    }

    else if (command == "LEFTMOVE"){
      myServo.write(90);
      esc.writeMicroseconds(1500);

    }

    else if (command == "RIGHTMOVE"){
      myServo.write(140);
      esc.writeMicroseconds(1500);

    }

    else if(command == "MOVE"){
      myServo.write(120);
      esc.writeMicroseconds(1500);
    }

    else{
      esc.writeMicroseconds(1000);
    }
  }
}

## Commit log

2025-02-22 Add files via upload
    The file contains the requested screenshots from the raspberry pi terminal
2025-03-11 Added .gitkeep to track autonomous_system_project_team_08 folder
2025-03-11 Add files via upload
    Added a screenshot for the printed results of the OLR node showing the rqt_graphs
    Added a screenshot for the printed results of the Teleop node showing the rqt_graphs
2025-03-12 Added Arduino_code folder with .gitkeep
2025-03-12 Added BLDC_SERVO_CONTROL file in Arduino_code
2025-03-12 Updated BLDC_SERVO_CONTROL in Arduino_code
2025-04-14 Added Hardware RaspberryPi Nodes
2025-04-14 Added Controller RaspberryPi Nodes
2025-04-14 Added Arduino Folder
2025-04-16 Added Arduino code
2025-04-16 Added Autonomous PCB
    [Autonomous_KiCAD8-B_Cu.gbr, Autonomous_KiCAD8-B_Mask.gbr, Autonomous_KiCAD8-B_Paste.gbp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]
2025-04-27 Added Milestone 4
    [model.sdf]
2025-05-10 Added Milestone 5 Simulation files
    [model.sdf]
2025-05-10 Added Simulation MS_05 Folder
    [model.sdf]
2025-05-18 Added Case 1 Hardware
2025-05-22 Added Noisy/Filtered data graphs
2025-06-07 Add new folder: Arduino_Code
